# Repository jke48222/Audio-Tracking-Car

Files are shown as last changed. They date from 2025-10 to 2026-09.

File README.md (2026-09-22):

# Audio Tracking Car

   

A Raspberry Pi–powered car that **localizes sound** with a dual‑channel analog front end and **tracks toward the desired source**. The system reads level‑decoded ADC signals from two band‑pass filtered microphone chains, computes left/right dominance, and drives two DC motors via an H‑bridge. Modes are selected with a 4‑bit **DIP switch** (audio tracking vs. figure‑drawing demos).

---

## Features

- **Audio localization & tracking** (single‑source and multi‑source strategies)
- **Closed‑loop drive** with wheel RPM sensing (optical end‑stops)
- **Figure‑drawing demos** (straight, curves, figure‑8) for validation
- **Emergency bump switch** to halt motion
- Modular Python code (`gpiozero`) with clear hardware abstraction

---

## Hardware

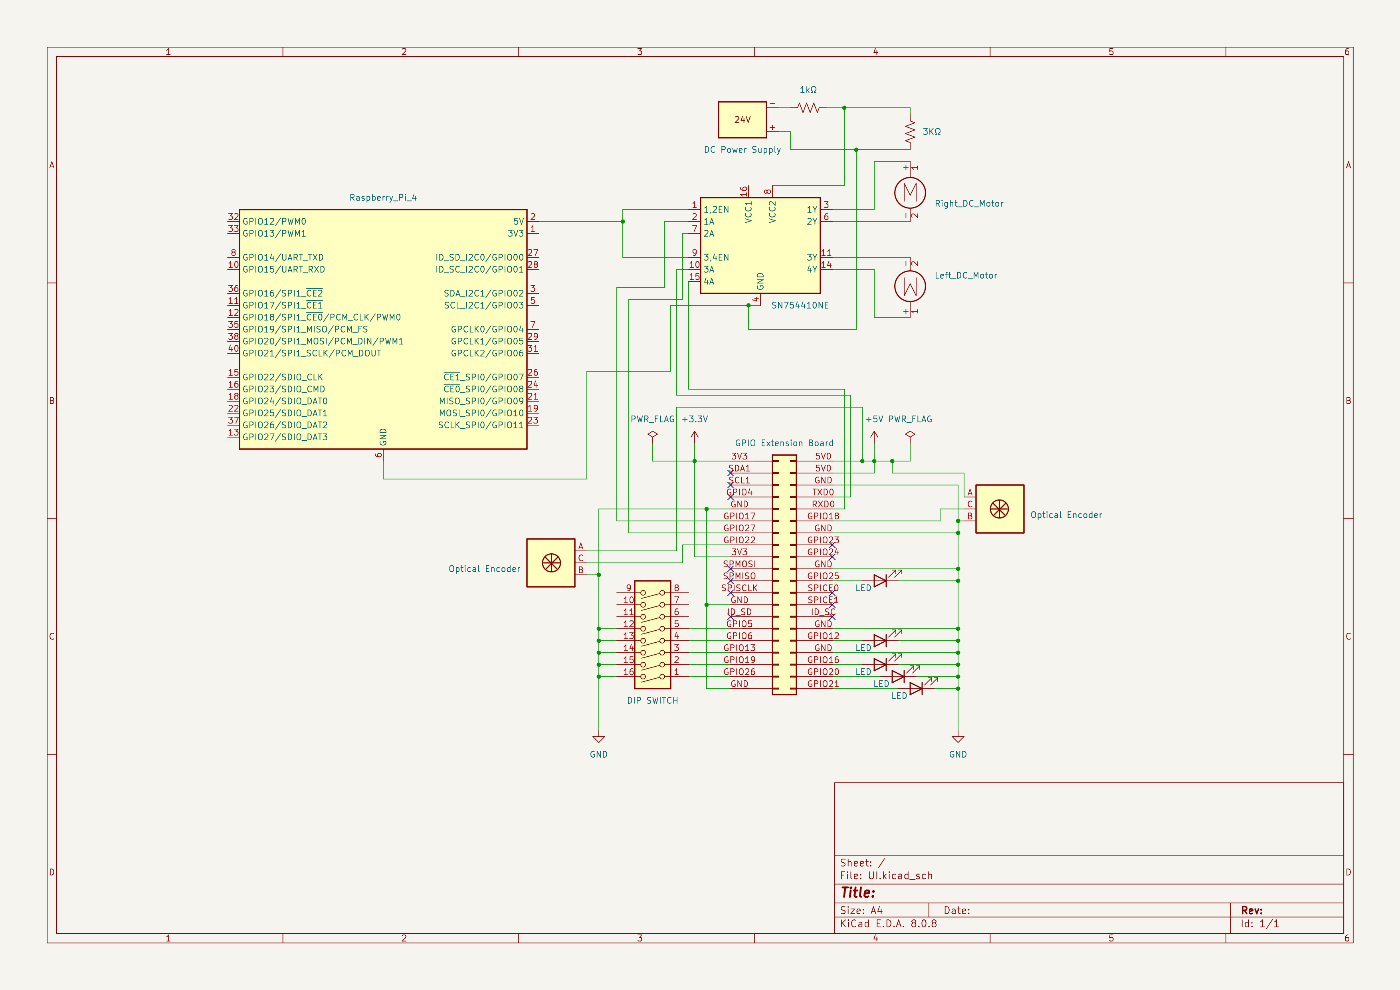
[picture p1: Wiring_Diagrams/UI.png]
System schematic, KiCad


Schematics in [`Wiring_Diagrams/`](Wiring_Diagrams): [H-Bridge](Wiring_Diagrams/H-Bridge.png), [PHP](Wiring_Diagrams/PHP.png), [UI](Wiring_Diagrams/UI.png).

- **Controller:** Raspberry Pi (GPIO via `gpiozero`)
- **Microphones:** 2× electret mic + analog chain (preamp → band‑pass → envelope/peak → level decode to GPIO)
- **Motor Driver:** H‑bridge (e.g., L293) or discrete MOSFET stage
- **Motors:** 2× DC gear motors, optical end‑stop disks for RPM
- **Switches:** 4‑bit DIP for mode select, bump switch for e‑stop
- **Power:** Isolated motor supply recommended

### GPIO Map (BCM)

| Function | Pin(s) | Notes |
|---|---|---|
| **Left Motor** | 27 (forward), 17 (back) | `gpiozero.Motor(27, 17)` |
| **Right Motor** | 15 (forward), 14 (back) | `gpiozero.Motor(15, 14)` |
| **Left Encoder** | 22 | `DigitalInputDevice(22)` |
| **Right Encoder** | 18 | `DigitalInputDevice(18)` |
| **Left ADC Levels** | 5, 11, 9, 10 | 4‑bit level from left audio chain |
| **Right ADC Levels** | 7, 8, 25, 23 | 4‑bit level from right audio chain |
| **Bump Switch** | 4 | Active‑HIGH with pull‑up |
| **DIP Switch** | 26 (MSB), 19, 13, 6 (LSB) | Mode select (see below) |

> Source: `Python/adc_logic.py`, `Python/rpm_motor_controller.py`, `Python/main.py`

---

## Modes (DIP Switch)

The 4 DIP inputs form a bit‑field used in `Python/main.py` to select behaviors:

- **Bit 3 (GPIO 26):** Stop/Run master enable  
- **Bit 2 (GPIO 19):** **Audio** tracking vs **Drawing** demos  
- **Bits 1–0 (GPIO 13, 6):** Sub‑mode selection (e.g., single vs multi‑source tracking; straight/curve/figure‑8)

> Flip the DIP switch while the program is running; changes are handled by callbacks that update the current behavior in real time.

---

## Software Layout

```
Audio-Tracking-Car/
├─ Python/
│  ├─ main.py                 # Mode control via DIP; ties modules together
│  ├─ audio_tracking.py       # Single & multi‑source tracking strategies
│  ├─ adc_logic.py            # GPIO readers for 4‑bit “ADC” levels + bump switch
│  ├─ rpm_motor_controller.py # Motor + encoder + RPM control helpers
│  └─ figure_drawing.py       # Straight, curves, figure‑8 demos
├─ CAD/                       # Car plate & switch holder models (STEP/SLDPRT)
├─ Wiring_Diagrams/           # ADC, Band‑Pass, H‑Bridge, UI schematics + PNGs
├─ Datasheets/                # Motors, L293, MOSFETs, optical end‑stop
└─ README.md                  # Project notes
```

---

## Setup

> Raspberry Pi OS (Bookworm/Bullseye), Python 3.9+

```bash
sudo apt update && sudo apt install -y python3 python3-pip
pip3 install gpiozero
```

If using GPIO as non‑root on newer Pi OS, enable interfaces:
```bash
sudo raspi-config  # Interfacing Options → enable as needed
```

---

## Run

From the repository root:
```bash
cd Python
python3 main.py
```

- Set the **DIP switch** to choose mode (see table above).  
- Use the **bump switch** (GPIO 4) as an emergency stop.  
- Ensure motor power is available and the H‑bridge is wired per `Wiring_Diagrams/H-Bridge.png`.

### Module Tests (manual)

```bash
python3 adc_logic.py            # Level decode sanity check
python3 rpm_motor_controller.py # Prints wheel RPM while motors spin
python3 audio_tracking.py       # Runs single-source demo by default
```

---

## Notes & Tips

- Balance microphone gains and ensure filters are **matched** across channels.  
- Use the **figure‑drawing** patterns to validate drivetrain before enabling audio tracking.  
- If wheel RPM is noisy, add debouncing or averaging in `rpm_motor_controller.py`.  
- Consider current limiting and flyback protection on the H‑bridge supply.

## License

MIT. See [LICENSE](LICENSE).

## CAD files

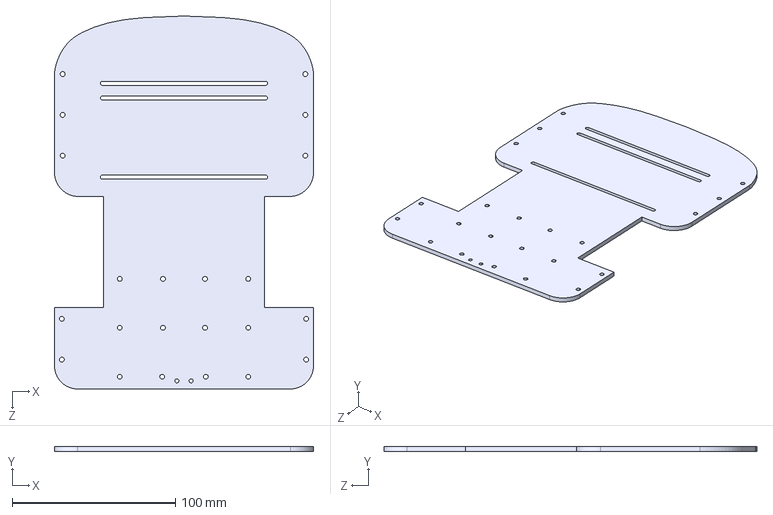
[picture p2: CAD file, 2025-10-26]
CAD/CarPlexiPlate.STEP
158.8 x 3.00 x 228.6 mm

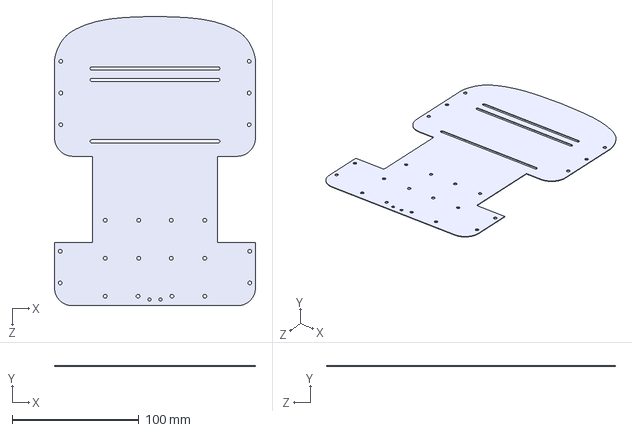
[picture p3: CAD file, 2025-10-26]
CAD/CarPlexiPlateQuickPrint.STEP
158.8 x 0.5 x 228.6 mm

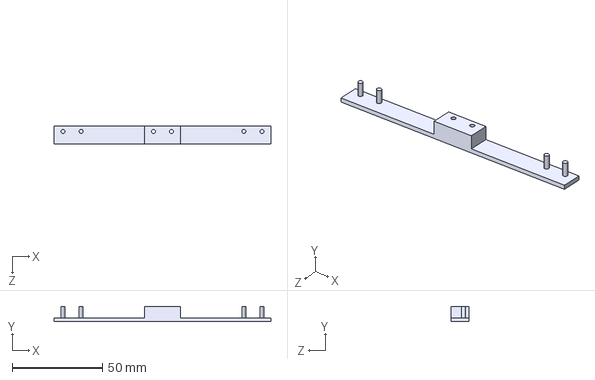
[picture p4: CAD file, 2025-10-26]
CAD/SwitchHolders.STEP
120.0 x 8.40 x 10.0 mm

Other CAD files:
CAD/CarPlexiPlate.SLDPRT
CAD/CarPlexiPlateQuickPrint.SLDPRT
CAD/SwitchHolders.SLDPRT

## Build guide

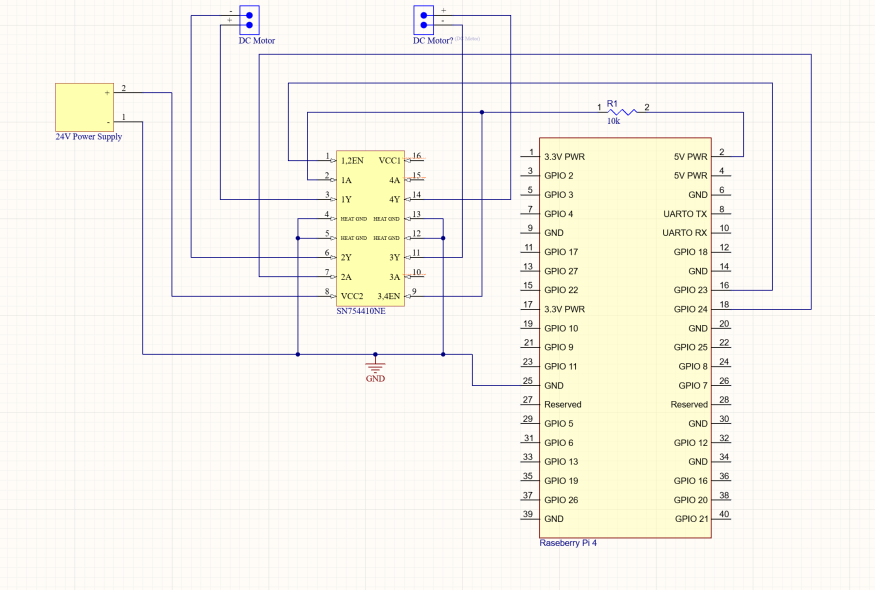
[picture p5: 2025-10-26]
Wiring_Diagrams/H-Bridge.png

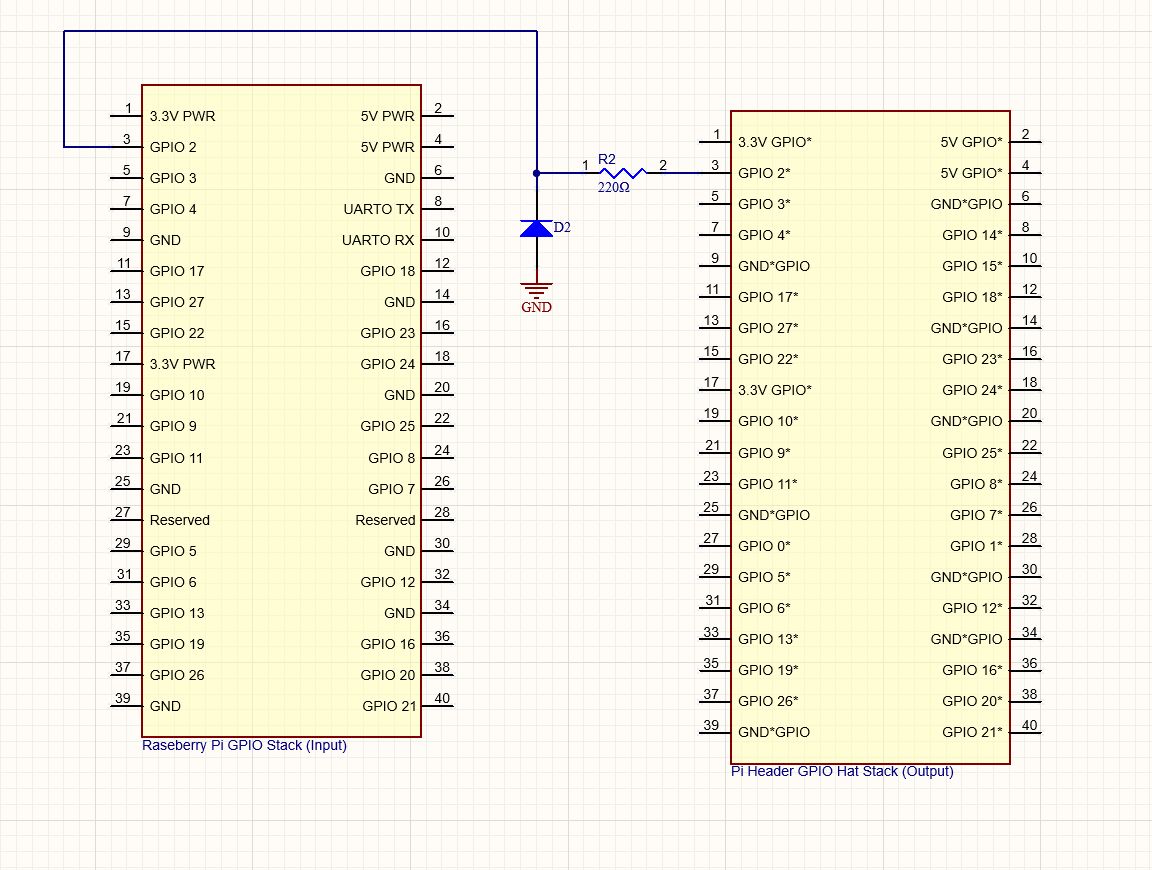
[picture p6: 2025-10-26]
Wiring_Diagrams/PHP.png

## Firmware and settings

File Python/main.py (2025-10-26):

"""
The main code file that houses the dip switch controls,
and will call the different functions depending on the input state
Dependent files include rpm_motor_controller, adc_logic, figure_drawing, and audio_tracking

"""


from gpiozero import Button, LED
from gpiozero.tools import negated
import time
import figure_drawing as fd
import audio_tracking as at
import adc_logic as adc


# create button classes for the dip switch
DIP_bit_2 = Button(19, bounce_time=.3)  # the audio or draw bit
DIP_bit_1 = Button(13, bounce_time=.3)  # subcategory
DIP_bit_3 = Button(26, bounce_time=.3)  # the stop or go bit
DIP_bit_0 = Button(6,  bounce_time=.3)  # subcategory


# create led class for the matching LEDS
DIP_LED_3 = LED(21)  # red
DIP_LED_2 = LED(20)  # yellow
DIP_LED_1 = LED(16)  # blue
DIP_LED_0 = LED(12)  # green


state_dict = {0: "Don't Move", 1: "single", 2: "multiple",
              3: "straight", 4: "figure 8", 5: "square", 6: "debug", 7: "nothing"}


class BitMap():
    def __init__(self):
        """
        Holds the states of the 4 different bits to update the output function
        """
        self.state = 0
        self.bit_3 = bool(DIP_bit_3.value)
        self.bit_2 = bool(DIP_bit_2.value)
        self.bit_1 = bool(DIP_bit_1.value)
        self.bit_0 = bool(DIP_bit_0.value)

    def change_state(self):
        """check the state of the combined bits to set the output state for the actions for the cars"""
        self.bit_3 = bool(DIP_bit_3.value)
        self.bit_2 = bool(DIP_bit_2.value)
        self.bit_1 = bool(DIP_bit_1.value)
        self.bit_0 = bool(DIP_bit_0.value)

        # creates a 3-bit binary to check the states
        bit_list = (self.bit_2, self.bit_1, self.bit_0)
        if self.bit_3 == False:
            match bit_list:
                case (False, False, False):
                    self.state = 1
                case (False, False, True):
                    self.state = 2
                case (False, True, False):
                    self.state = 7
                case (False, True, True):
                    self.state = 7
                case (True, False, False):
                    self.state = 3
                case (True, False, True):
                    self.state = 4
                case (True, True, False):
                    self.state = 5
                case (True, True, True):
                    self.state = 6
                case _:  # this is a catch all in none of the others worked
                    self.state = 0

            # prints the state as it changes in real time
            print(state_dict[self.state])


def led_setup():
    # used to reference the bitmap functions
    DIP_LED_3.source = DIP_bit_3
    DIP_LED_2.source = DIP_bit_2
    DIP_LED_1.source = DIP_bit_1
    DIP_LED_0.source = DIP_bit_0
    bit_map.change_state()  # makes sure the LEDs match on startup

def adc_c8_led():
    DIP_LED_3.source = negated(adc.right_adc1)
    DIP_LED_2.source = negated(adc.right_adc1)
    DIP_LED_1.source = negated(adc.right_adc3)
    DIP_LED_0.source = negated(adc.right_adc4)
    

def adc_c6_led():
    DIP_LED_3.source = negated(adc.left_adc1)
    DIP_LED_2.source = negated(adc.left_adc2)
    DIP_LED_1.source = negated(adc.left_adc3)
    DIP_LED_0.source = negated(adc.left_adc4)

def switch_setup():
    # callback functions to update the bitmap
    for button in [DIP_bit_0, DIP_bit_1, DIP_bit_2, DIP_bit_3]:
        button.when_activated = bit_map.change_state
        button.when_deactivated = bit_map.change_state


def main_loop():
    """Main loop that handles the dip switch input, and 6 state output"""
    try:
        while True:
            print("Waiting on input")
            DIP_bit_3.wait_for_active(10)  # stands by waiting for bit 3

            while bit_map.bit_3:
                print("3")
                # three second grace period to un-flip bit 3 or run away before it drives
                time.sleep(1)
                print("2")
                time.sleep(1)
                print("1")
                time.sleep(1)
                if DIP_bit_3.value == 0:  # checks to cancel if bit was flipped, acting as a debounce method
                    print("Canceled")
                    break
                bit_map.change_state()

                try:
                    match bit_map.state:  # main function choices to execute code
                        case 1:
                            # Single audio tracking
                            adc_c8_led()
                            at.single_source(adc.adc_c8)
                        case 2:
                            # Multiple audio tracking
                            adc_c8_led()
                            at.multiple_source(adc.adc_c8)
                            adc_c6_led()
                            at.multiple_source(adc.adc_c6)
                        case 3:
                            # straight
                            fd.straight()
                        case 4:
                            # Figure 8
                            fd.figure_8()
                        case 5:
                            # Square
                            fd.square()
                        case 6:
                            # debug, for checking gain on mics
                            print("checking c8")
                            adc_c8_led()
                            adc.adc_level_check(adc.adc_c8)
                            print("next frequency C^")
                            time.sleep(2)
                            adc_c6_led()
                            adc.adc_level_check(adc.adc_c6)

                        case 7:
                            print("Not assigned, still didn't moved")
                        case _:
                            # usually can happen on startup
                            print("something is wrong, nothing happened . . .")

                except:
                    # if a function fails it doesn't break the loop
                    print("error try again")
                led_setup()
                print("Complete, please reset")  # always triggers unless break
                DIP_bit_3.wait_for_inactive()  # have to unset bit 3 to re-loop

    except:
        print("\nExiting...")


bit_map = BitMap()  # main class object created that is referenced for all of the decisions


if __name__ == "__main__":  # only runs the code when this file in run directly, great for imports later if needed
    print("startup")
    led_setup()
    switch_setup()
    main_loop()

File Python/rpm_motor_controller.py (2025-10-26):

"""
Controls how the car will move, incorporates our transfer function, 
called by the audio tracking and figure drawing files

"""

from gpiozero import Motor, CompositeOutputDevice, DigitalInputDevice, PWMOutputDevice, Robot  # type: ignore
import time
import threading

"""
old init functions, used for reference

pin_17 = PWMOutputDevice(17,frequency=100)
pin_27 = PWMOutputDevice(27,frequency=100)
pin_14 = PWMOutputDevice(14,frequency=100)
pin_15 = PWMOutputDevice(15,frequency=100)

left_motor = CompositeOutputDevice(pin_17, pin_27)
right_motor = CompositeOutputDevice(pin_14, pin_15) 

audio_car = CompositeOutputDevice(left_motor, right_motor)
"""

# using built in gpiozero libraries to assign gpio pin outs
left_motor = Motor(27, 17)
right_motor = Motor(15, 14)
left_encoder = DigitalInputDevice(22)
right_encoder = DigitalInputDevice(18)
audio_car = Robot(left_motor, right_motor)

# constants
disk_slots = 20
target_rpm = 200


class RPM():
    """
    Calculates the rpm of the functions, handles the callback of the encoders,
    and updates the speed of the motors to using the transfer function 
    """

    def __init__(self, motor: Motor, slots, rpm):
        self.rpm = 0
        self.count = 0
        self.disk_slots = slots
        self.target_rpm = rpm
        self.start_time = time.time()
        self.duty = .8
        self.motor = motor
        self.start_count = 0

    def update(self):
        """ Callback to update with the optical encoders"""
        self.count += 1

    def set_target(self, rpm):
        """ Set the new target rpm """
        self.target_rpm = rpm

    def thread(self):
        """ Run to update RPM to Update speed"""
        self.end_count = self.count 
        self.diff_count = self.end_count - self.start_count #counts the time difference
        if self.diff_count == 0 or self.diff_count < 0:
            self.diff_count = 1

        self.rpm = min(1, ((self.diff_count)/.1 * (1/20))) #using the time difference, computes the rpm
        print(f"Motor Speed : {self.rpm:.2f} RPM")
        self.start_count = self.count

        self.motor_ratio = (abs(self.target_rpm)/self.rpm)
        self.duty = max(0.1, min(1, self.motor_ratio))
        self.set_speed() # updates the speed to match the speed of the target

    def set_speed(self):
        """ Run to update speed of the motors"""
        match self.target_rpm:
            case 0:
                self.motor.value = 0
            case n if n > 0:
                self.motor.value = (self.duty)
                print(self.motor.value)
            case n if n < 0:
                print(self.motor.value)
                self.motor.value = (-self.duty)


# main inits
left_rpm = RPM(left_motor, disk_slots, target_rpm)
right_rpm = RPM(right_motor, disk_slots, target_rpm)
left_encoder.when_activated = left_rpm.update
right_encoder.when_activated = right_rpm.update


# main loop type
def calculate_rpm():
    time.sleep(.1)
    left_rpm.thread()
    right_rpm.thread()

# can be re-run the clear variables


def setup():
    left_rpm = RPM(left_motor, disk_slots, target_rpm) #inits the rpm to control the specified motors
    right_rpm = RPM(right_motor, disk_slots, target_rpm)

    left_rpm.set_speed()
    right_rpm.set_speed()

# does not always need to be called


def loop():  # test loop that prints out the current RPMs of both motors
    while True:
        time.sleep(1)
        print(left_rpm.rpm)
        print(right_rpm.rpm)


# only runs when this file is run directly
if __name__ == "__main__":
    setup()
    threading.Thread(target=calculate_rpm, daemon=True).start()
    loop()
